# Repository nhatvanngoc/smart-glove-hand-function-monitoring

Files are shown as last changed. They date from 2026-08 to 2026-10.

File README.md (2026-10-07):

# NGHIÊN CỨU VÀ PHÁT TRIỂN GĂNG TAY THÔNG MINH HỖ TRỢ ĐÁNH GIÁ VÀ THEO DÕI CHỨC NĂNG VẬN ĐỘNG BÀN TAY TRONG PHỤC HỒI CHỨC NĂNG SAU ĐỘT QUỴ

> **Học sinh:** Văn Ngọc Nhật Anh (11A2) + Nguyễn Duy Quân (12A1) · **GVHD:** Lê Công Long · **Trường:** THPT Quảng Trị, Quảng Trị
> **Trạng thái hồ sơ:** pha **cơ sở lý thuyết & thiết kế** (`DEC-PHASE-001`) · **chưa có kết quả thực nghiệm** · **bản đã nộp:** [`docs/DE_CUONG.pdf`](docs/DE_CUONG.pdf) (15 trang, 2026-09-26)
> **Tên đã nộp = tên `DEC-TOPIC-019`** (dưới đây). Tên mới mà README ngày 2026-09-19 ghi là "chốt" (`DEC-TITLE-001`) **chưa từng được duyệt trong `DECISION_LOG.md`** → đã hạ thành đề xuất chờ hủy (`DEC-TITLE-002`); chi tiết: [`research/reviews/2026-09-27_decuong_pdf_sync.md`](research/reviews/2026-09-27_decuong_pdf_sync.md)

**Tên tiếng Anh (hồ sơ ISEF/ViSEF bản dịch):**

> *A low-cost smart glove with directional piezoresistive sensing for quantitative hand motor-function assessment and longitudinal monitoring in post-stroke rehabilitation*

**Phụ đề kỹ thuật (dùng ở đầu báo cáo, không nằm trong tên):**

> *Găng tay đo lực ép bên trên khung cứng + tầm vận động chủ động/thụ động từng ngón, kèm ngưỡng tin cậy đăng ký trước khi đo.*

**Lĩnh vực dự thi (đã nộp):** Hệ thống nhúng (Embedded Systems) · **Thời gian:** 09/2026–01/2027 · **Địa điểm:** phòng sáng tạo trường + nhà riêng · chờ `DEC-TEAM-001` phê chuẩn vào log.

**Câu nói với giám khảo (12 giây):**

> Một găng tay đo **lực ép theo hướng** ở từng ngón, chạy tại nhà, kèm **bộ tiêu chí khiến mỗi con số tự nói được nó có đáng tin hay không** — để khoảng trống giữa hai lần tái khám không còn là hộp đen.

---

## Mục lục

[1. Luận điểm của đề tài](#1-luận-điểm-của-đề-tài) ·
[2. Vấn đề, có số](#2-vấn-đề-có-số) ·
[3. Câu hỏi nghiên cứu và điều kiện giết](#3-câu-hỏi-nghiên-cứu-và-điều-kiện-giết) ·
[4. Nguyên lý hoạt động](#4-nguyên-lý-hoạt-động) ·
[5. Ba đại lượng dẫn xuất và quy tắc đơn vị](#5-ba-đại-lượng-dẫn-xuất-và-quy-tắc-đơn-vị) ·
[6. Phương pháp: bộ kiểm chứng 10 ngưỡng](#6-phương-pháp-bộ-kiểm-chứng-10-ngưỡng) ·
[7. Kế hoạch và ngân sách](#7-kế-hoạch-và-ngân-sách) ·
[8. Tính mới — và bộ tiêu chí đang dùng để tự chấm](#8-tính-mới--và-bộ-tiêu-chí-đang-dùng-để-tự-chấm) ·
[9. Giới hạn tự khai](#9-giới-hạn-tự-khai) ·
[10. Bằng chứng của chính hồ sơ này](#10-bằng-chứng-của-chính-hồ-sơ-này) ·
[11. Bản đồ repo](#11-bản-đồ-repo) ·
[12. Thiết lập & quy trình](#12-thiết-lập--quy-trình) ·
[13. Metadata repo GitHub](#13-metadata-repo-github)

---

## 1. Luận điểm của đề tài

Đề tài **không** tuyên bố một nguyên lý vật lý mới và **không** bán một nguyên mẫu. Nó tuyên bố ba thứ, theo thứ tự bảo vệ được giảm dần:

1. **Một kiến trúc cơ khí** — mảng áp trở đặt trên **vách cứng** của ốp ngón, cấu hình cầu vi sai hai vách (bản nộp: `R_ref = 10 kΩ` → INA333 G=10 → ADS1115 16-bit), để đo riêng **thành phần lực ép bên**: đại lượng tăng khi người bệnh chống lại tầm vận động, tức là thứ mà cảm biến gập góc *về bản chất* không phân biệt được.
2. **Một thiết kế phép đo** — `AROM` rồi `PROM` trên cùng ngón, cùng phiên, ở **hai tốc độ kéo** (vì phản ứng căng cơ phụ thuộc tốc độ). `GAP = PROM − AROM` (bản nộp 2026-09-26; README cũ ghi ngược dấu) chính là phép thử phân tách *"chưa cố"* khỏi *"bị giữ lại"*.
3. **Một lớp tự kiểm chứng** — ngưỡng `MDC`/`ICC`/`CV`/trôi **đăng ký trước khi đo**, mỗi phiên mang cờ `UNRELIABLE` khi vượt ngưỡng, và **lỗi được tiêm có chủ đích** trên rig để chứng minh cờ đó không phải đồ trang trí.

> **Câu chốt cho hội đồng:** phần (1) đã có tiền lệ ở tầng phần tử cảm biến, phần (2) là lựa chọn phương pháp luận, **phần (3) là phần đề tài này mạnh hơn cả một số công trình đã công bố** — và cũng là phần rẻ nhất để làm đúng.

## 2. Vấn đề, có số

| Đại lượng | Giá trị | Nguồn (đã kiểm) |
|---|---|---|
| Đột quỵ ở Việt Nam — hiện mắc | **1.541**/100.000 (95% UI 1.431–1.679) | *Global Epidemiology* 2025;9:100199 · [DOI](https://doi.org/10.1016/j.gloepi.2025.100199) |
| Mới mắc / tử vong | **222**/100.000/năm · **135.999** ca tử vong (dẫn đầu nhóm tim mạch) | như trên |
| Tổn thương vận động chi trên, giai đoạn sớm | **~80%** | Cochrane 2014 CD010820 (trích Langhorne 2009) · [DOI](https://doi.org/10.1002/14651858.CD010820.pub2) |
| Liệt chi trên hoàn toàn lấy lại chức năng hữu ích sau 6 tháng | **~50%** | như trên (trích Kwakkel 2003) |
| Còn vấn đề tay sau **4 năm** | **~50%** | như trên (trích Broeks 1999) |
| Độ tin cậy của việc **người bệnh tự đếm số lần tập** | `MDC ≈ 31 %`; đếm nhầm **100–200 lần/giờ** | *Sensors* 2022;22(18):6938 · [DOI](https://doi.org/10.3390/s22186938) |
| Giá hệ thống PHCN bàn tay tại nhà đã FDA chấp thuận | **350–6.000 USD** | *Device* (Cell Press) 2024 |

**Suy ra vấn đề:** di chứng bàn tay kéo dài **nhiều tháng đến nhiều năm**, trong khi nhịp đánh giá lâm sàng là **1–3 tháng**; và cách thay thế đang dùng (tự báo cáo) **đã được đo là không đủ tin cậy để làm đơn vị phân tích**. Khoảng giữa hai lần tái khám là một hộp đen — không biết có tập không, tập đúng hay sai, tiến bộ hay chững.

*(Con số "cỡ 1,5 triệu người đang sống sau đột quỵ ở Việt Nam" là **phép nhân của đề tài** từ tỉ lệ hiện mắc × dân số, không phải số in trong bài báo — nêu rõ như vậy ở mọi chỗ dùng nó.)*

## 3. Câu hỏi nghiên cứu và điều kiện giết

**RQ chính** (quyết định đề tài sống/chết):

> **R1.** Đáp ứng lực–hướng từ mảng áp trở trên vách khung có **đủ nhạy và đủ ổn định** để phát hiện thay đổi chức năng bàn tay theo tuần — **vượt trên** biên độ nhiễu/trôi của chính hệ thống đo — và **không** sinh ra cảnh báo tiến triển giả?

**RQ phụ:**

> **R2.** Dấu hiệu gập/duỗi có suy ra được **chỉ từ mẫu đáp ứng trên vách**, không cần encoder, và kết hợp được với góc IMU để tái tạo tư thế bàn tay đủ trung thực cho chuyên gia đọc?
> **R3.** Các chỉ số trích xuất có **đồng biến** với công cụ chuẩn (Box & Block / ARAT / lực kế cầm tay) ở mức đủ để dùng làm thông tin bổ sung giữa hai lần tái khám?

| RQ | Cửa quyết định | Nếu fail thì sao |
|---|---|---|
| R1 | **`GATE 0`** (bản nộp: `C1.2` + `C1.8` là hai ô giết, tương ứng `G0.1` + `G0.7` cũ) | Không có chuỗi số liệu nào để nói về diễn tiến → đề tài đổi thành **báo cáo phương pháp + kết quả âm tính** (vẫn nộp được, vẫn có giá trị) |
| R1 | **`GATE C`** (trôi 28 ngày, nhiệt–ẩm, tháo/lắp) | Dừng đề tài theo đúng nghĩa đã ghi trong `research/protocols/06` |
| R2 | `GATE A`/`GATE B` trên ≥ 1 ngón | Bỏ tái tạo 3D, giữ `GAP`/`EI` |
| R3 | **Chỉ sau IRB** — nằm ngoài phạm vi đề cương này | Không nêu giả thuyết R3 như kết quả; chỉ là thiết kế dự phòng |

**Điều đề tài không hỏi, và do đó không được claim:** không đo lực tuyệt đối trên ngón, không đo góc khớp tuyệt đối từ ADC, không đo hoạt động cơ, không chẩn đoán, không thay thế đánh giá lâm sàng, không cam kết hiệu quả phục hồi.

## 4. Nguyên lý hoạt động

```
Co cơ / bị duỗi thụ động ──► ngón ép vào VÁCH CỨNG của ốp ngón
   ► áp suất tiếp xúc p = F/A_c nén mảng Velostat
   ► ΔR/R = γ · Δp/p₀                       (γ = độ nhạy áp trở, p₀ = F_p/A_c)
   ► cầu vi sai hai vách: d = S(lòng) − S(mu), R_ref = 10 kΩ (bản nộp)
   ► INA333 G=10 ──► mux CD74HC4067 ──► ADS1115 16-bit (62,5 µV/LSB)
   ► ESP32-S3: IIR fc=10 Hz + Notch 50 Hz ──► BLE ──► Orange Pi 5 Pro
   ► auto-zero 3 s + ô tham chiếu + nhãn "Nghi vấn" (2 vòng lặp kín)
   ► EI · GAP · RAL          (KHÔNG phải newton, KHÔNG phải độ suy từ ADC)
```

**Hai kết quả rút ra từ mô hình, và cả hai đều kiểm chứng được bằng tay** (`docs/02` §5.5, `CLM-MET-003`):

1. `A_c` **triệt tiêu ở bậc nhất** ⇒ kích thước mảng **không** phải vấn đề tỉ số tín hiệu/nhiễu; nó là vấn đề cơ khí (áp suất phân bố lại, độ lặp lại khi tháo/lắp). ⇒ Không cần mua mảng to hơn.
2. Thiết kế chỉ sống trong một **cửa sổ tiền tải `F_p` chặn hai phía**: dưới thì không đủ nhạy — với `n_eff ≈ 11`, `V_EX = 3,1 V`, `LSB = 1,51 mV` và `ΔV ≥ 8 LSB` tại `ΔF = 1 N` thì `F_p ≤ 68·γ·ΔF` (γ = 0,5 ⇒ `F_p ≲ 34 N`); trên thì điện trở nguồn cao làm **mux không kịp ổn định ở 20 Hz**. **"Cửa sổ đó có rỗng không" chính là nội dung của GATE 0.**

> `100 kΩ / 10-bit / 1,51 mV` là **ngân sách thiết kế** trong `docs/04` §1, **không phải kết quả đo** — cấm dùng như số liệu.
> Bản nộp 2026-09-26 dùng chuỗi khác (`CLM-HW-003`, chờ `DEC-HW-005`): ADS1115 + INA333 + `R_ref = 10 kΩ` + SHT30 + 1 IMU LSM6DS3 — xem `docs/04` §8.
> Số học cửa sổ preload phải tính lại với LSB mới sau khi `DEC-HW-005` được chốt.

**Đính chính hai chỗ cũ trong README này:** (1) bản trước viết "thiết kế **không dùng IMU**" — đúng hơn: **dấu gập/duỗi** lấy từ mẫu vách mà không cần encoder (ý của `docs/01` §4), còn **góc và tốc độ kéo** thì bản nộp chỉ còn **1 IMU ở mu tay** (bù nghiêng), không còn 6 IMU đo góc khớp — **nguồn đo góc cho `GAP` là câu hỏi mở I7**, chờ `DEC-HW-005` trả lời. (2) bản trước viết `GAP = AROM − PROM` — **bản nộp quy ước `GAP = PROM − AROM ≥ 0°`**; đã sửa đồng bộ ở §5.

Phân cấp thuật ngữ (bắt buộc dùng đúng): [`docs/bao_cao/GLOSSARY.md`](docs/bao_cao/GLOSSARY.md) — **vật liệu Velostat** ≠ **sensing element** (Velostat + đồng tự dính + cấu trúc sandwich) ≠ **mảng sensing element** ≠ **hệ thống cảm biến** (mảng + ESP32-S3 + firmware).

## 5. Ba đại lượng dẫn xuất và quy tắc đơn vị

| Đại lượng | Định nghĩa (bản nộp 2026-09-26, `CLM-DEF-001` — chờ `DEC-METRIC-002` phê chuẩn) | Điều kiện phải in kèm | Đơn vị |
|---|---|---|---|
| **`EI`** (Effort Index) | trung vị biến thiên phổ của tín hiệu vi sai 12 kênh, chuẩn hóa theo vận tốc góc cùng phiên; công thức/cửa sổ/ngưỡng **cố định trước khi đo**, chỉ so sánh nội bộ cùng giao thức | ngón · tốc độ kéo · hướng dẫn bằng giọng nói | **không thứ nguyên** (công thức tường minh còn nợ) |
| **`GAP`** | **`PROM − AROM`** trên cùng ngón, cùng phiên (≥ 0°, theo giao thức; **không** tự suy nguyên nhân yếu/co cứng/khớp) | PROM kéo thụ động chậm · AROM gập chủ động tối đa · **hai tốc độ kéo** | độ — **nguồn đo góc còn mở (I7)**, **không** suy từ ADC |
| **`RAL`** | nấc tải **nhỏ nhất** (thang 120 g → 0 g) đạt tỉ lệ hoàn thành nhịp **P_complete ≥ 80 %** (10 chu kỳ gập/duỗi mỗi nấc, trên giàn + phantom) | tải (g) · vị trí khớp · tốc độ | **gam + bậc tải** (đặc trưng giao thức kiểm định, **không** phải bằng chứng hồi phục) |

**Cấm trong mọi bảng số:** `ADC → newton` (không có load cell trên ngón; load cell chỉ là chuẩn đối chứng ở rig) · `ADC → độ` · dùng `RAL` như chỉ số lâm sàng.
> Lịch sử định nghĩa (để không lẫn khi đọc tài liệu cũ): README/`DE_CUONG_NOP_TRUONG.md` cũ ghi `GAP = AROM − PROM`, `EI = median\|d\|/(1+κ\|v̂\|)`, `RAL = thực/yêu cầu ∈ [0,1]`; `docs/02` §7.3 ghi `GAP` mẫu chuẩn hóa, `EI = E/(E+E_nền)` — xem sổ R2–R4 trong sync review §5.3.

## 6. Phương pháp: bộ kiểm chứng 10 ngưỡng (bản nộp: M1–M6 + C1.1–C1.10)

> Ngưỡng được viết ra và **đóng chốt trước khi có bất kỳ số liệu nào**, và **không** chỉnh lại sau khi thấy số. Một ngưỡng không đạt ⇒ báo cáo **fail** ở ngưỡng đó. Cấm viết "GATE 0 pass" khi `C1.2` hoặc `C1.8` fail. Bảng dưới là ngưỡng **đã nộp** (`CLM-MET-005`, chờ `DEC-METRIC-002` phê chuẩn); cột cuối ghi chỗ đổi so với bộ G0.x cũ.

| ID (nộp) | Câu hỏi | Ngưỡng đã nộp | Đổi so với G0.x |
|---|---|---|---|
| **C1.1** | Sàn nhiễu mạch đo là bao nhiêu? | `Vpp ≤ 5 mV` / 5.000 mẫu tĩnh | chốt luôn định nghĩa B + ngưỡng tuyệt đối |
| **C1.2** 🎯 | Có tồn tại `F_p` vừa đủ nhạy vừa đủ ổn định? | `SNR ≥ 18 dB` (≈8×) tại `ΔF = 1 N`, ≥10/12 kênh | đơn vị LSB → dB, phạm vi 10/12 kênh |
| C1.3 | Mảng có thật sự là áp kế? | `γ ≥ 0,25` (≥10/12 kênh), `R² ≥ 0,90` | **R² 0,95 → 0,90** |
| C1.4 / C1.5 | Lặp lại giữa chu kỳ / giữa **ngày**? | `CV ≤ 5 %` · `CV ≤ 8 %` (3 ngày, tháo/đeo lại, trên phantom) | **ICC → CV**, nới 5 %→8 % |
| C1.6 / C1.7 | Đường lên có trùng đường xuống? Có bị lún khi giữ tải? | `h ≤ 18 %` · `creep ≤ 8 %` (giữ 60 s @ 5 N) | **15 %→18 %** · **đổi định nghĩa creep** |
| **C1.8** 🎯 | Tín hiệu có trôi chậm hơn biên độ cần đo? | trôi/tín hiệu ≤ 2,0 sau 10 ngày (qua auto-zero) | **bỏ** điều kiện so ΔV@1N |
| C1.9 | Các mảng có đủ giống nhau để so sánh giữa ngón? | độ rải `γ ≤ ±40 %` (+ bảng chuẩn hóa) | khớp |
| C1.10 | Cấu hình kênh đọc kịp không? | `fs ≥ 20 Hz` đồng thời 12 kênh | khớp (⚠️ PDF §8.1/§9.1 ghi 50 Hz — I1) |

🎯 = ô giết đề tài. **Cách chạy GATE 0 mà không cần một dòng code:** `research/protocols/08a` — phiếu in được, chuẩn lực là **khối lượng đã cân** (`F = m·g`, không trễ, không cần hiệu chuẩn điện tử), mọi phép tính chỉ là trừ số nguyên. Kế hoạch đầy đủ + cây fail: `research/protocols/08` (giữ 10 ô chờ chốt; bảng đối chiếu G0↔C1: sync review §4).

## 7. Kế hoạch và ngân sách

```
Lớp 0 (GATE 0)    Mảng Velostat + đồng tự dính + jig in + khối lượng chuẩn + đồng hồ đo
                  ── chuẩn lực = F = m·g, KHÔNG cần load cell ──►  0,12–0,65 triệu đ
Lớp 1 (GATE A/B)  3 ngón (cái, trỏ, giữa) × 2 khớp, cầu vi sai hai vách + 1 IMU LSM6DS3
                  + INA333 + ADS1115 + 2×CD74HC4067 → ESP32-S3 (20 Hz)  ► +0,57–1,50 triệu đ
Lớp 2 (GATE D/F)  Orange Pi 5 Pro (log nguồn thô + dashboard) + rig E4/E5 (vít me,
                  phanh từ, tải chuẩn) + phantom silicone          ► +1,10–2,50 triệu đ
Lớp 3 (lâm sàng)  IRB + bệnh viện + n ≥ 20                          ► CHƯA MỞ — ngoài đề cương
```

> Bản nộp đặt thêm 3 ràng buộc sản phẩm: giá găng mục tiêu **< 1,5 triệu đ** · khối lượng đeo **< 150 g** · trễ toàn hệ thống **≤ 500 ms** (M5).

| Tổng hợp | Tiền mặt cần chi (vật tư đã có sẵn đã được trừ) |
|---|---|
| Hết GATE 0 | **0,12–0,65 triệu đ** |
| Hết GATE A+B | + 0,57–1,50 triệu đ |
| Hết GATE F | ≈ **1,8–4,7 triệu đ** |
| Kịch bản phải mua tất cả | ≈ 6,5–12 triệu đ |
| **Chi phí tối đa nếu GATE 0 fail** | **≤ 0,65 triệu đ** — thiết kế để cắt lỗ sớm |

Quy tắc: mỗi lớp **chỉ mở khi lớp trước pass**; vật tư được cấp/đã có ghi là **"được cung cấp"**, không ghi thành "chi phí 0 đ"; giá thương mại chỉ là **mốc so sánh có nguồn**, không phải giá của đề tài. Bảng theo hạng mục: `docs/DE_CUONG_NOP_TRUONG.md` §7; trạng thái vật tư: `research/context/EQUIPMENT_AND_ACCESS.md`.

**Kế hoạch theo cửa, không theo lịch thi** (repo **không có ngày nộp**, và không ai được bịa một cái): 8 pha từ "chốt ngưỡng → GATE 0 → A → B → C → D → E → F", chi tiết `research/protocols/06`–`08`.

## 8. Tính mới — và bộ tiêu chí đang dùng để tự chấm

> **Bộ tiêu chí: ViSEF/ISEF**, không phải tạp chí kỹ thuật. Đề tài **không** có nguyên lý mới và không tự đo mình bằng chuẩn cần nguyên lý mới + dataset + đối chứng lâm sàng. Mọi nhận định "mới/không mới" phải kèm tên bộ tiêu chí (`DEC-NOV-001` chờ chủ dự án chốt mức).

| Hướng được coi là mới | Kiểm chứng ngược đã làm | Kết luận hiện hành |
|---|---|---|
| Vách cứng phân biệt hướng lực | Phần tử áp điện trở **trên vách** có từ **2015** (`SRC-SIDEWALL-PIEZO-2015`); vỏ cứng khớp nối + da áp điện trở **2026** (`SRC-ARTGLOVE-2026`, 2048 taxel, 22 DoF) | **Cải tiến cấu hình + cách lập luận**, không phải nguyên lý |
| Găng đo lực cho người đột quỵ | Đối thủ gần nhất: Lin et al., *Sensors* 2022;22(19):7212 — **19 IMU + 1 bóng áp lực**, n = 14, **có IRB** | Họ thắng về **học máy + cỡ mẫu**; đề tài phải thắng ở **cơ khí tạo phân tách + lớp tin cậy**, không ở số cảm biến |
| Găng có chức năng tập/hỗ trợ | ironHand (JRATE 2016 **và** J Rehabil Med 2018;50:598–606, n = 5, **không** dùng thiết bị đo lực chuẩn hoá làm kết quả chính) | Đề tài **bỏ** chức năng tác động để dồn vào phép đo |
| Ghi nhận tại nhà thay cho tự báo cáo | Manumeter (RCT, n = 20, *Sensors* 2022) — MDC 31 %, 100–200 đếm nhầm/giờ | Đây là **bằng chứng cho khoảng trống**, không phải cho thiết bị của ta |
| "Hệ thống đầu tiên" | Khảo sát hệ thống găng tự chế (arXiv 2405.15417) + găng đo từ 2006 + Neofect Smart Glove (132 g, flex + 9 DoF, dashboard cho chuyên gia) | **Cấm nói.** Mẫu câu duy nhất được phép: *"chưa tìm thấy công trình nào kết hợp [A+B] cho [nhóm X]"*, và chỉ khi đã có số tự đo |

Bằng sáng chế đã tra: **US20150233779A1** (Waltop) — **đã abandoned**; **CN116954366A** (ĐH Đông Nam Á) — **pending**. FTO = `PARTIAL` vì **chưa đọc toàn văn điểm yêu cầu bảo hộ** ⇒ chỉ được nói "đã tra cứu, không phát hiện xung đột trực tiếp". Chi tiết + nghĩa vụ trích dẫn: `research/reviews/2026-09-19_prior_art_novelty_gate1.md`.

## 9. Giới hạn tự khai

| # | Giới hạn | Cách đề tài xử lý |
|---|---|---|
| 1 | **Chưa có một kết quả đo nào** | nêu ngay đầu README và đầu đề cương; không nói vòng quanh |
| 2 | Chưa hiệu chuẩn `ΔR → N`; ADC không quy đổi ra newton/độ | dùng counts + `EI` không thứ nguyên |
| 3 | Đối tượng tự kiểm chứng ban đầu là **một người** (chính người chế tạo) | chặn mọi kết luận lâm sàng tới khi có IRB + n ≥ 20 |
| 4 | Velostat phi tuyến, trễ, từ biến, trôi, nhạy ẩm | biến thành ngưỡng đo được (G0.5–G0.7), không tuyên bố đã khắc phục |
| 5 | Không có bằng chứng hiệu quả lâm sàng | tuyên bố dừng ở "cung cấp phép đo đáng tin" |
| 6 | `RAL` không phải chỉ số lâm sàng | chỉ dùng để so sánh cấu hình máy + chứng minh phát hiện lỗi |
| 7 | `GAP`/`EI` không thay thế FMA/ARAT/MAS | mục tiêu là **tần suất đo**, không phải thay công cụ chuẩn |

## 10. Bằng chứng của chính hồ sơ này

| Loại | Số lượng | Kiểm ở đâu |
|---|---|---|
| Nguồn đã vào sổ, có locator + mức đã đọc | **147** | `research/evidence/SOURCE_LEDGER.csv` |
| Tuyên bố, kèm cấp bằng chứng + hành động còn lại | **27** | `research/claims/CLAIM_LEDGER.csv` |
| Quyết định có ngày + chủ sở hữu + trạng thái | **38** | `research/context/DECISION_LOG.md` |
| Nhật ký truy vấn ngoài (**kể cả lần tìm không thấy**) | **81** | `research/queries/QUERY_LOG.jsonl` |
| Phiếu đo/thực nghiệm đã thiết kế, chưa chạy | **10 ngưỡng · 7 gate · 8 buổi bench** | `research/protocols/06`–`08a` |
| Số liệu đo của đề tài | **0** | `research/bench/logs/` — đang trống, và đó là trạng thái thật |

Quy tắc chống tự nâng cấp: **không** nâng mức bằng chứng; **một lần tìm không thấy = `UNVERIFIED`**, không phải "không tồn tại"; số liệu giả lập phải dán nhãn giả lập; agent đề xuất, **chủ dự án phê duyệt**. Toàn bộ ở [`AGENTS.md`](AGENTS.md).

## 11. Bản đồ repo

| Nhóm | File | Vai trò |
|---|---|---|
| **Nộp trường** | [`docs/DE_CUONG_NOP_TRUONG.md`](docs/DE_CUONG_NOP_TRUONG.md) | Đề cương hoàn chỉnh: 4 trụ + M1–M6 + ngân sách + hạn chế tự khai + Phụ lục A chống-claim |
| Đề tài | [`docs/01_Topic_Definition.md`](docs/01_Topic_Definition.md) | Tên đã chốt, vấn đề, khoảng trống, RQ1–R3, phạm vi (`A.4`: **không** phải thiết bị điều trị) |
| Lý thuyết | [`docs/02_Theoretical_Foundation.md`](docs/02_Theoretical_Foundation.md) | Sinh lý hồi phục, thang đo, cơ sinh học, vật liệu áp trở, mô hình §5.5, `EI`/`GAP`/`RAL`, INT8 |
| Prior art & sáng chế | [`docs/03_Literature_Gap_Analysis_Plan.md`](docs/03_Literature_Gap_Analysis_Plan.md) | Kế hoạch rà soát 2011–2026; §7 phương pháp tra cứu sáng chế + hồ sơ thất bại |
| Phần cứng | [`docs/04_Hardware_Architecture.md`](docs/04_Hardware_Architecture.md) | Kênh, MUX, ngân sách nhiễu/độ phân giải (**ngân sách thiết kế**, không phải kết quả) |
| Cơ khí — khung ốp ngón | [`hardware/cad/finger_shell_hinge/`](hardware/cad/finger_shell_hinge/README.md) | **Đề xuất** (`CLM-HW-004`/`DEC-HW-006`, chưa in/chưa đo): khung ốp 1 đốt ngón kiểu vỏ-sò, bản lề trục + ngàm cài, thay cơ chế xỏ ngón + bu-lông kẹp — CAD tham số CadQuery, xuất STEP/STL |
| Soạn thảo | [`docs/05_De_Cuong_Dang_Ky_DRAFT.md`](docs/05_De_Cuong_Dang_Ky_DRAFT.md) | **Outline nội bộ** (không nộp) + §8b các chỗ chủ dự án cần sửa |
| Mẫu báo cáo | [`docs/OUTLINE_BAOCAO_VISEFD.md`](docs/OUTLINE_BAOCAO_VISEFD.md) · [`docs/bao_cao/`](docs/bao_cao/) | Khung A/B/C + A.1–A.7 + GLOSSARY |
| Kiểm chứng | [`research/protocols/06`](research/protocols/06_glove_hand_GATE_experiment.md) · [`07`](research/protocols/07_ral_phantom_and_ktv_interview.md) · [`08`](research/protocols/08_gate0_execution_plan.md) · [`08a`](research/protocols/08a_gate0_bench_sheets.md) | Master 7 gate · RAL/phantom + phiếu tham khảo chuyên gia · kế hoạch GATE 0 · **phiếu đo in được, không code** |
| Vật tư & tiếp cận | [`research/context/EQUIPMENT_AND_ACCESS.md`](research/context/EQUIPMENT_AND_ACCESS.md) | Đã có / chưa chắc / cần mua + 4 bước chạy GATE 0 |
| Đánh giá chiến lược | [`research/reviews/2026-09-19_project_ceiling.md`](research/reviews/2026-09-19_project_ceiling.md) | Trần theo từng trục + **nguyên tắc giải ngân theo lớp** + quy tắc dừng |
| Benchmark | [`research/reviews/2026-09-19_benchmark_xe_lan_ALS_QG2025.md`](research/reviews/2026-09-19_benchmark_xe_lan_ALS_QG2025.md) | **Nội bộ.** Kiểm đếm một báo cáo từng giải Nhất quốc gia → định cỡ hình thức 15–20 trang, ≥1,3 ảnh/bảng mỗi trang. **Cấm trích trong hồ sơ nộp** (`DEC-SCOPE-003`) |
| Nhật ký đo | [`research/bench/logs/`](research/bench/logs/) | Một file mỗi buổi; **bản gốc không bao giờ bị sửa**; header nhắc lại ngưỡng đã chốt |
| Chỉ mục | [`INDEX.md`](INDEX.md) · [`research/README.md`](research/README.md) · [`AGENTS.md`](AGENTS.md) | Sơ đồ file, quy ước workspace, luật của repo |

## 12. Thiết lập & quy trình

Yêu cầu: Git, Python 3.10+, Bash.

```bash
python3 -m venv .venv && . .venv/bin/activate
python -m pip install --upgrade pip && python -m pip install -r requirements.txt
bash scripts/bootstrap_research_tooling.sh
python scripts/check_research_environment.py --strict
python scripts/build_context_bundle.py --budget-chars 40000     # -> research/generated/ (đã gitignore)
```

**Ba việc còn lại, đúng thứ tự:**

1. ☐ **Chủ dự án chốt 6 quyết định đồng bộ bản nộp** (`DEC-SYNC-001`/`TEAM`/`TITLE-002`/`HW-005`/`METRIC-002`/`SCOPE-005`, sync review §6) **rồi chốt 10 ô** `Chốt?` trong `research/protocols/08` §7 (việc này **không** ai làm thay được).
2. ☐ Chạy GATE 0 bằng `research/protocols/08a` → mỗi buổi = 1 file log + 8 ảnh; **kể cả buổi fail cũng phải lưu**.
3. ☐ Thay dự toán bằng **báo giá/hoá đơn thật** → `DEC-BUDGET-001` (id dự kiến trong `2026-09-19_project_ceiling.md`, chưa tạo); chỉ khi đó mới xét giải ngân Lớp 1.

Luồng chuẩn cho mỗi thay đổi lớn: đọc `research/context/PROJECT_SNAPSHOT.md` → log truy vấn (`scripts/research_log.py`) → cập nhật `SOURCE_LEDGER`/`CLAIM_LEDGER` → chạy review protocol → cập nhật snapshot + `INDEX.md` → dựng lại bundle.

## 13. Đổi tên repo + metadata GitHub (chủ dự án chạy — agent không có quyền Administration)

Repo hiện tên `smart-glove-hand-function-monitoring` với **description vẫn là mô tả đề tài cũ**. Bốn lệnh dưới đây chạy theo thứ tự, copy nguyên khối được:

```bash
# 1) Doi ten repo cho khop ten de tai moi (quyen admin cua chu du an)
gh repo rename stroke-hand-monitoring-glove --repo nhatvanngoc/smart-glove-hand-function-monitoring

# 2) Cap nhat remote cua may local theo ten moi
git remote set-url origin https://github.com/nhatvanngoc/stroke-hand-monitoring-glove.git
git push -u origin HEAD

# 3) Mo cua cho cai ten moi: description + topic + homepage (xoa topic cu neu can)
gh repo edit --description "Nghiên cứu, thiết kế găng tay giám sát và đánh giá khả năng vận động bàn tay trong phục hồi chức năng chủ động sau đột quỵ — giai đoạn cơ sở lý thuyết, chưa có kết quả đo; toàn bộ prior art có DOI tại research/evidence/" \
  --add-topic stroke --add-topic rehabilitation --add-topic hand-function --add-topic wearable-sensors \
  --add-topic piezoresistive --add-topic velostat --add-topic esp32-s3 --add-topic isef --add-topic visef

# 4) kiem tra
gh repo view --json name,description,repositoryTopics -q '"\(.name)\n\(.description)\nTopics: \([.repositoryTopics[].name]|join(", "))"'
```

**Nếu không muốn đổi tên repo**, chỉ chạy bước 3 (description/topics) — README và tên đề tài trong repo đã khớp nhau, GitHub redirect tự động nếu sau này đổi tên.

*Ba lựa chọn tên repo, xếp theo khuyến nghị:* `stroke-hand-monitoring-glove` (đúng 3 từ khoá: đối tượng – việc – thiết bị) · `hand-motion-glove` (ngắn, dễ nhớ, hơi rộng) · `smart-glove-stroke-rehab` (dễ đọc nhưng giữ chữ "smart" mà tên đề tài mới đã bỏ).

---

### Lịch sử cập nhật gần nhất

| Ngày | Việc |
|---|---|
| 2026-09-27 | **Đồng bộ bản nộp `docs/DE_CUONG.pdf` (2026-09-26):** đội hình 2 người + GVHD + timeline + lĩnh vực Nhúng; tên quay về `DEC-TOPIC-019` (`DEC-TITLE-001` chờ hủy); `GAP = PROM − AROM`; ngưỡng C1.x; kiến trúc ADS1115+INA333; +7 nguồn/+3 claim; 6 quyết định chờ chốt (`DEC-SYNC-001`…`DEC-SCOPE-005`) |
| 2026-09-19 (lượt 4) | README dựng lại theo cấu trúc hồ sơ khoa học (luận điểm · RQ + điều kiện giết · nguyên lý · 10 ngưỡng · tự khai); đề xuất tên mới (ghi nhầm là "chốt" — đã sửa 2026-09-27, chờ `DEC-TITLE-002`) |
| 2026-09-19 (lượt 3) | Đề cương nộp `docs/DE_CUONG_NOP_TRUONG.md`; sửa 2 lỗi trích dẫn trong `A.1`; thi hành `DEC-ROLE-001` (không nêu danh tính người được tham khảo) |
| 2026-09-19 (lượt 1–2) | Prior art lượt 1–2 (novelty dịch từ cơ chế sang lớp thống kê); GATE 0 plan + phiếu đo không code; đánh giá trần dự án + mức đầu tư theo lớp |

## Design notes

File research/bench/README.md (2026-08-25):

# Bench metrology execution area

This directory contains **empty templates and validation tooling only**. It contains no hardware measurement and must never be cited as a result.

## Gate-2 execution preconditions

1. A traceable/characterized reference load cell or test fixture is available.
2. The sensor unit, electrode layout, conditioning circuit, ADC reference, scan order and firmware hash are recorded.
3. Raw ADC and reference timestamps can be retained together.
4. The protocol operator completes `templates/session_manifest.csv` and `templates/perturbation_log.csv` without participant identifiers.
5. Reference-load calibration and nominal repeatability are run before any perturbation is interpreted.

`templates/` contains headers only. Raw measurements, photos, private subject mappings, downloaded tools and generated analysis outputs follow repository ignore/privacy rules and must be stored outside tracked templates until an owner-approved data-management plan exists.

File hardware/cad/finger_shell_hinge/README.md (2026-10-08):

# Khung ốp 1 đốt ngón tay — cơ chế BẢN LỀ + NGÀM CÀI (thay cơ chế "xỏ ngón vào ống kín")

> **Trạng thái:** `PROPOSED` — bản vẽ CAD tham số, **chưa in, chưa đo lực/preload thật, chưa có người dùng thử**.
> **Claim/quyết định liên quan:** `CLM-HW-004` (`research/claims/CLAIM_LEDGER.csv`), `DEC-HW-006` (`research/context/DECISION_LOG.md`).
> **Phạm vi:** làm đúng **1 đốt ngón tay trước** (theo yêu cầu), chưa nhân ra 3–5 ngón.
> Theo `AGENTS.md`: đây là **thiết kế cơ khí trên giấy**, không phải kết quả đo, không phải tuyên bố "đã hết đau/đã thoải mái" — mọi tính từ công thái học (thoải mái, nhanh, không đau) đều là **mục tiêu thiết kế cần kiểm chứng sau khi in**, không phải kết luận.

---

## 1. Vấn đề đang muốn sửa

Thiết kế ốp ngón hiện có trong `docs/04_Hardware_Architecture.md` (§6, §8) là một **ống gần như kín**, có **bu-lông kẹp vi chỉnh preload** siết quanh ngón tay để ép hai vách cảm biến (Velostat) vào hai bên lòng/mu ngón. Nhược điểm với đúng nhóm người dùng của đề tài (sau đột quỵ, bàn tay liệt/co cứng, khó chủ động gập — xem `README.md` §1 mục tiêu đề tài):

- Phải **luồn/ép đốt ngón co cứng qua một vòng gần kín** → đau, khó, nhiều khi cần 2 người.
- Siết bu-lông quanh ngón đang co cứng → khó canh lực, dễ siết lệch, dễ gây khó chịu thêm.

**Yêu cầu của chủ dự án (nguyên văn rút gọn):** "trên đốt ngón có 1–2 bản lề, mở ra để đặt khung vào phía trên tay bệnh nhân, bên dưới chỉ cần cài lại — bệnh nhân không phải cố xỏ ngón tay vào một cách đau đớn."

→ Bài toán cơ khí: biến ống kín thành **vỏ-sò (clam-shell)** có 1 cạnh mở được (bản lề) và 1 cạnh khóa nhanh (ngàm cài), vẫn giữ được 2 vách cứng đối xứng (mu/lòng) để dán sensing element như kiến trúc đo vi sai đã chọn (`docs/04` §3.2, "mỗi khớp có cặp sensing element đối xứng trên hai vách đối diện").

## 2. Tham khảo thị trường (tham khảo nguyên lý — KHÔNG sao chép hình học)

| Sản phẩm/khái niệm | Nguyên lý lấy làm tham khảo | Khác với thiết kế ở đây |
|---|---|---|
| **Oval-8® Finger Splint** (nẹp ngón PIP/DIP bán thương mại) — [AliMed](https://www.alimed.com/products/oval-8-finger-splint) (`SRC-OVAL8-ALIMED`) | "Open design eliminates skin issues and discomfort" — vòng **hở sẵn một khe**, lắp bằng cách lách qua khe đàn hồi, không phải xỏ kín từ đầu ngón | Oval-8 là **một khối nhựa đàn hồi duy nhất** (tự bung ra rồi tự khép lại nhờ độ đàn hồi vật liệu), không có bản lề trục hay ngàm cài rời. Thiết kế ở đây dùng **bản lề trục in 3D + chốt** vì PETG/PLA không đàn hồi tốt như nhựa nhiệt dẻo y tế của Oval-8 → không thể chỉ dựa vào lò xo vật liệu để vừa giữ chặt vừa dễ mở. |
| **Nẹp ngón nhiệt dẻo 2 mảnh** — [Cults3D / RafaelNaranjo](https://cults3d.com/en/3d-model/various/finger-orthosis-thermoformable-3d-printed-rafaelnaranjo) (`SRC-FINGERORTHO-CULTS3D`) | 2 mảnh cứng nối bằng vùng mềm, cố định bằng **dây chun/Velcro xuyên khe** | Thiết kế ở đây giữ ý tưởng "khe xuyên dây đai" làm **lớp khóa an toàn phụ** (mục 6), nhưng khóa chính là ngàm cơ khí chứ không phải dây đai. |
| **HERO Grip Glove** (robot hỗ trợ bàn tay sau đột quỵ, PMC7045638) (`SRC-HEROGLOVE-PMC2020`) | Benchmark công thái học: **don < 5 phút, doff < 1 phút**, thiết kế riêng cho tay liệt/co cứng, không cần tự chủ động gập để đeo | Dùng làm **mốc so sánh mục tiêu** (không phải của thiết bị này) cho tiêu chí "thời gian mang/tháo" đã nêu ở `docs/04` §6. |
| Bản lề khớp ống in 3D kiểu "piano hinge" (kiến thức phổ biến trong cộng đồng in 3D, không gắn với 1 sản phẩm cụ thể) | Khớp ống so le (knuckle) + chốt rời — in được bằng FDM mà không cần vật liệu đàn hồi | Áp dụng trực tiếp cho cạnh bản lề của khung ốp. |

**Tra cứu bằng sáng chế:** chưa thực hiện cho riêng cơ cấu bản lề/ngàm này (khác phạm vi với tra cứu `US20150233779A1`/`CN116954366A` đã ghi ở `README.md` §8, vốn là về *mảng cảm biến*, không phải *cơ cấu kẹp cơ khí*). Cơ cấu bản lề-ngàm nói chung là kỹ thuật phổ biến trong hộp/vỏ nhựa và nẹp y tế; **FTO cho riêng chi tiết này chưa tra**, không tuyên bố mới.

## 3. Nguyên lý cơ cấu đề xuất

```
                    CẠNH BẢN LỀ (trái)             CẠNH NGÀM CÀI (phải)
                   ┌──────────────┐               ┌──────────────┐
  Nửa MU TAY (A)   │  3 khớp ống   │   vách cứng   │  khối ngàm    │
  — cố định,       │  (knuckle)    │  + hốc dán    │  2 nấc răng   │
  đặt lên trước    │  xen kẽ với B │  Velostat     │  (cố định)    │
                   └──────┬───────┘               └──────┬───────┘
                          │ chốt Ø2mm xuyên suốt          │
  Nửa LÒNG TAY (B) ┌──────┴───────┐               ┌──────┴───────┐
  — xoay quanh     │  2 khớp ống   │   vách cứng   │  tay đòn đàn  │
  bản lề để đóng   │  (knuckle)    │  + hốc dán    │  hồi, có móc  │
                   └──────────────┘               └──────────────┘

  Thao tác: (1) đặt đốt ngón vào lòng nửa A (đang để hở, B đang mở ra ~150°)
            (2) gập B xuống quanh trục chốt
            (3) ấn nhẹ tay đòn ở B cho móc "tách" vào 1 trong 2 nấc răng của A
            (4) (tuỳ chọn) luồn dây đai/Velcro qua khe phụ ở 2 đầu để khóa an toàn lớp 2
  Mở ra: lấy ngón tay ra bằng cách bẩy nhẹ tay đòn ra khỏi nấc răng — không cần tháo chốt.
```

Ảnh xem nhanh (dựng từ STL, xem thêm trong `out/renders/`):

| Trạng thái MỞ | Trạng thái ĐÓNG |
|---|---|
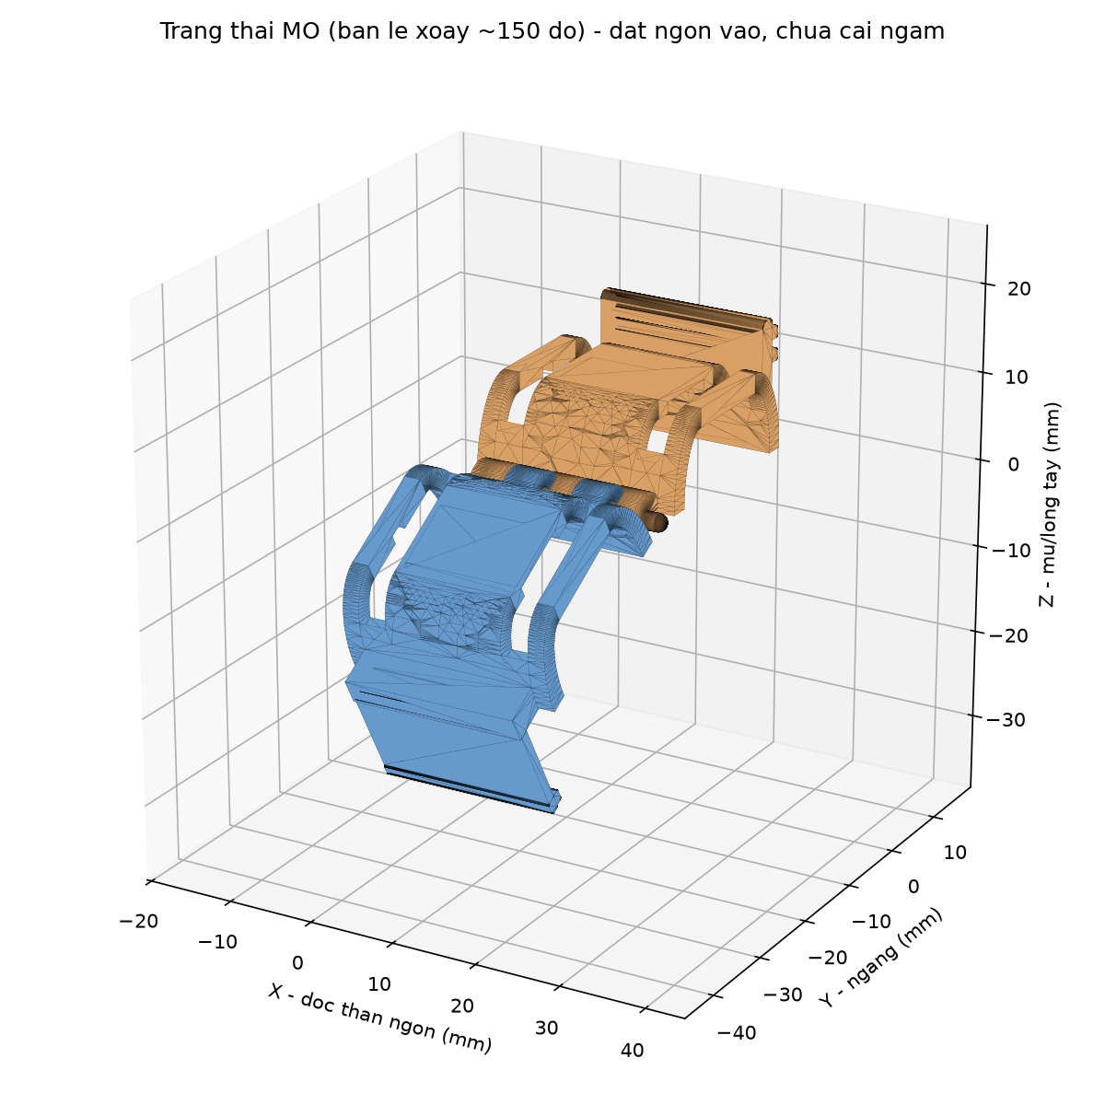
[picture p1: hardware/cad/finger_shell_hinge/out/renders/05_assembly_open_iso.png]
open
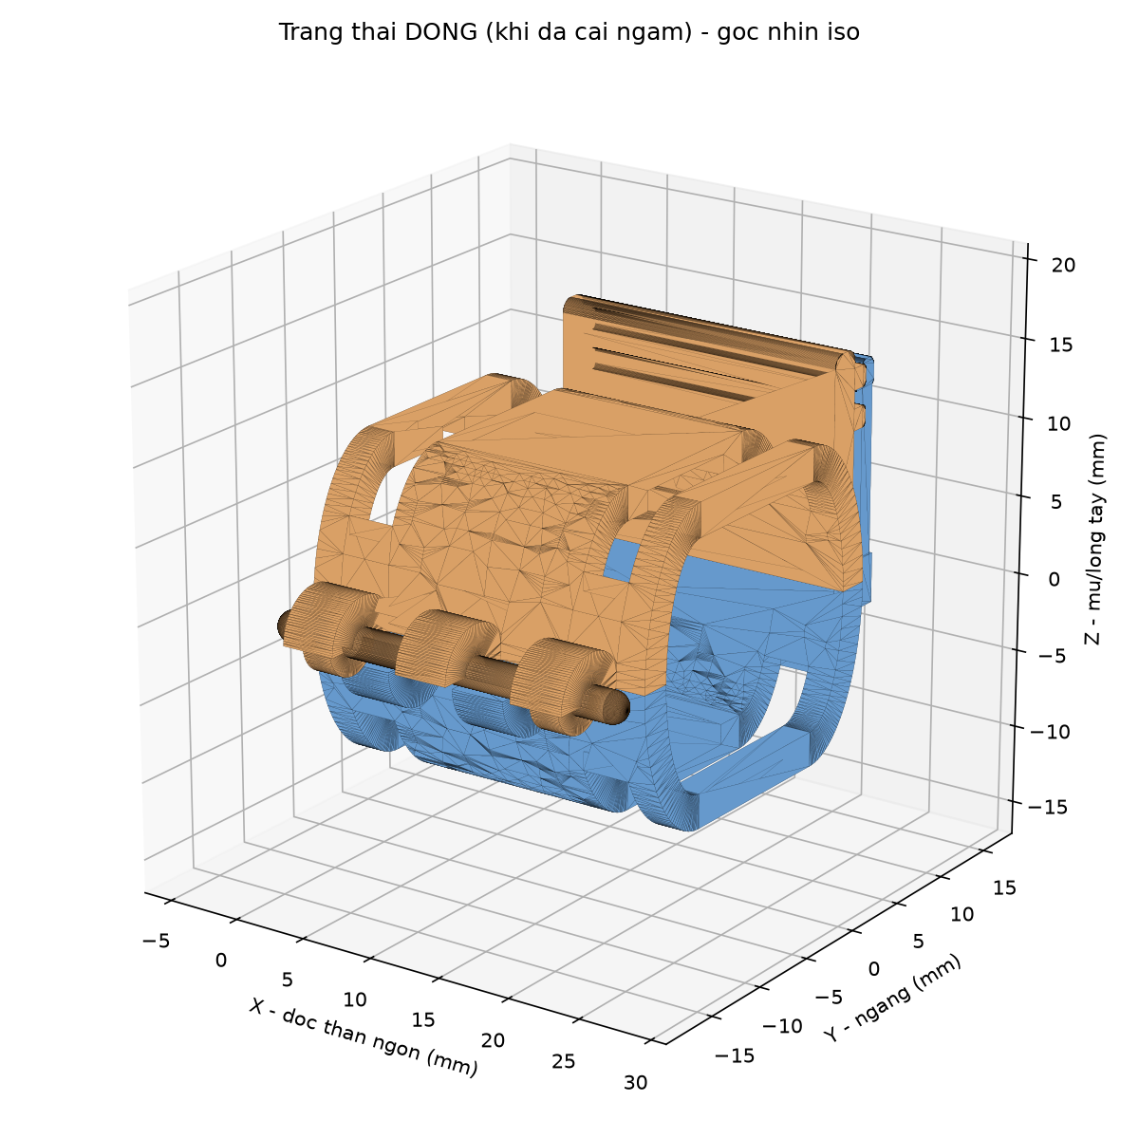
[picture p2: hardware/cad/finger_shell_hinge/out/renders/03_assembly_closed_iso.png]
closed
|  |  |
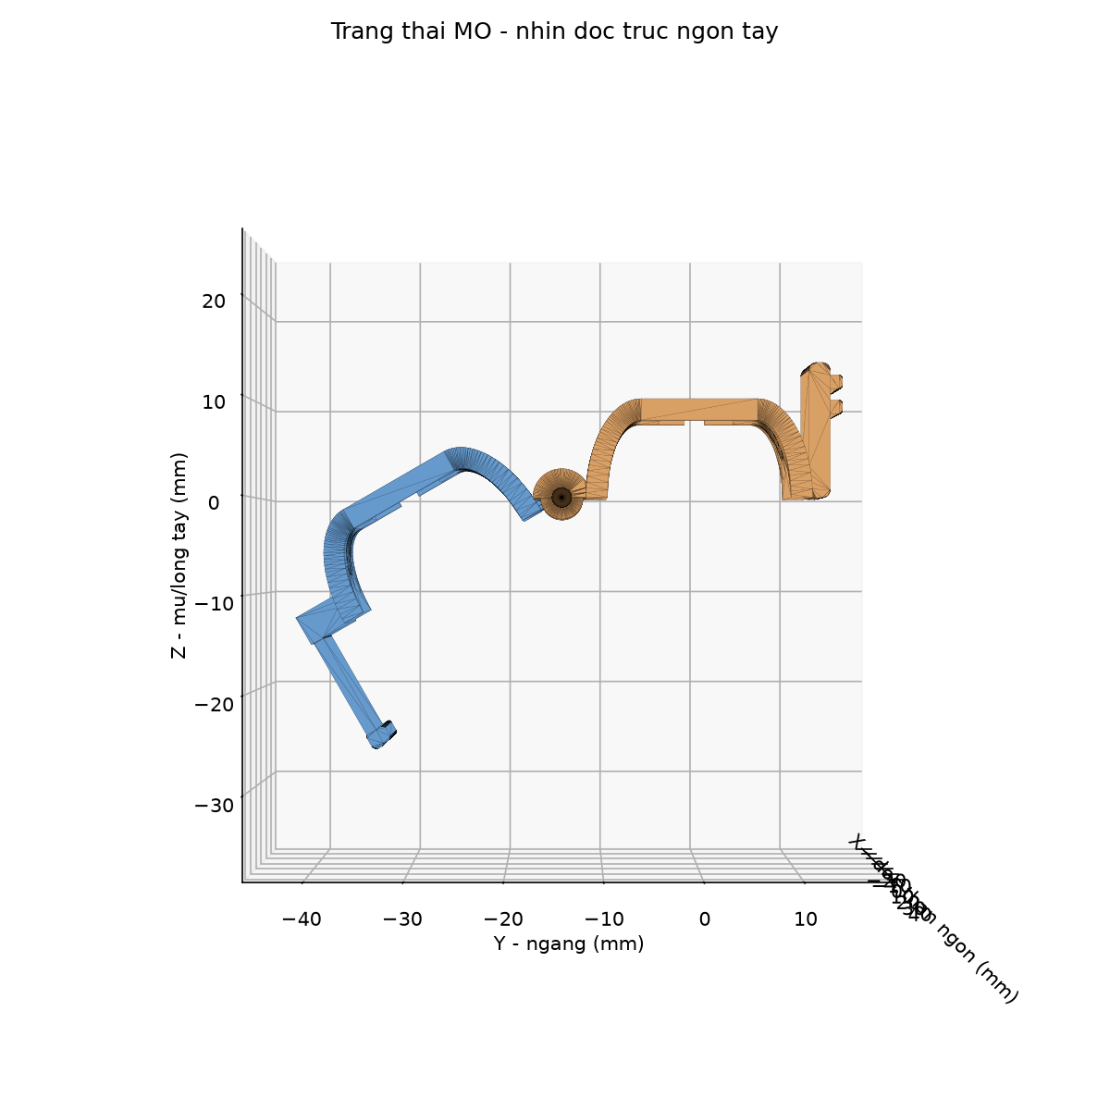
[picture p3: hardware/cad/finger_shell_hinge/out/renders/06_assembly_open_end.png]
open-end
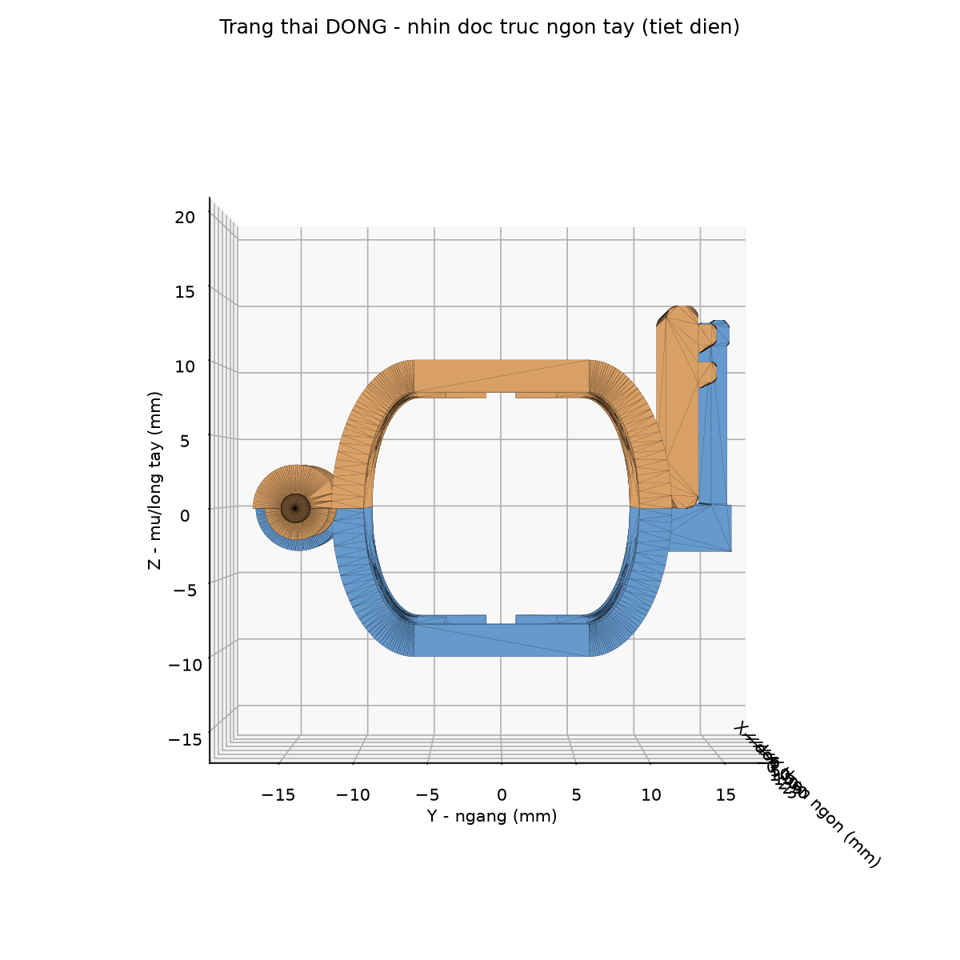
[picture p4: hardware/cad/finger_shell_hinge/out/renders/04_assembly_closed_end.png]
closed-end
|  |  |

Từng mảnh riêng:

| Nửa mu tay (A, cố định, mang khối ngàm) | Nửa lòng tay (B, xoay quanh bản lề, mang tay đòn) |
|---|---|
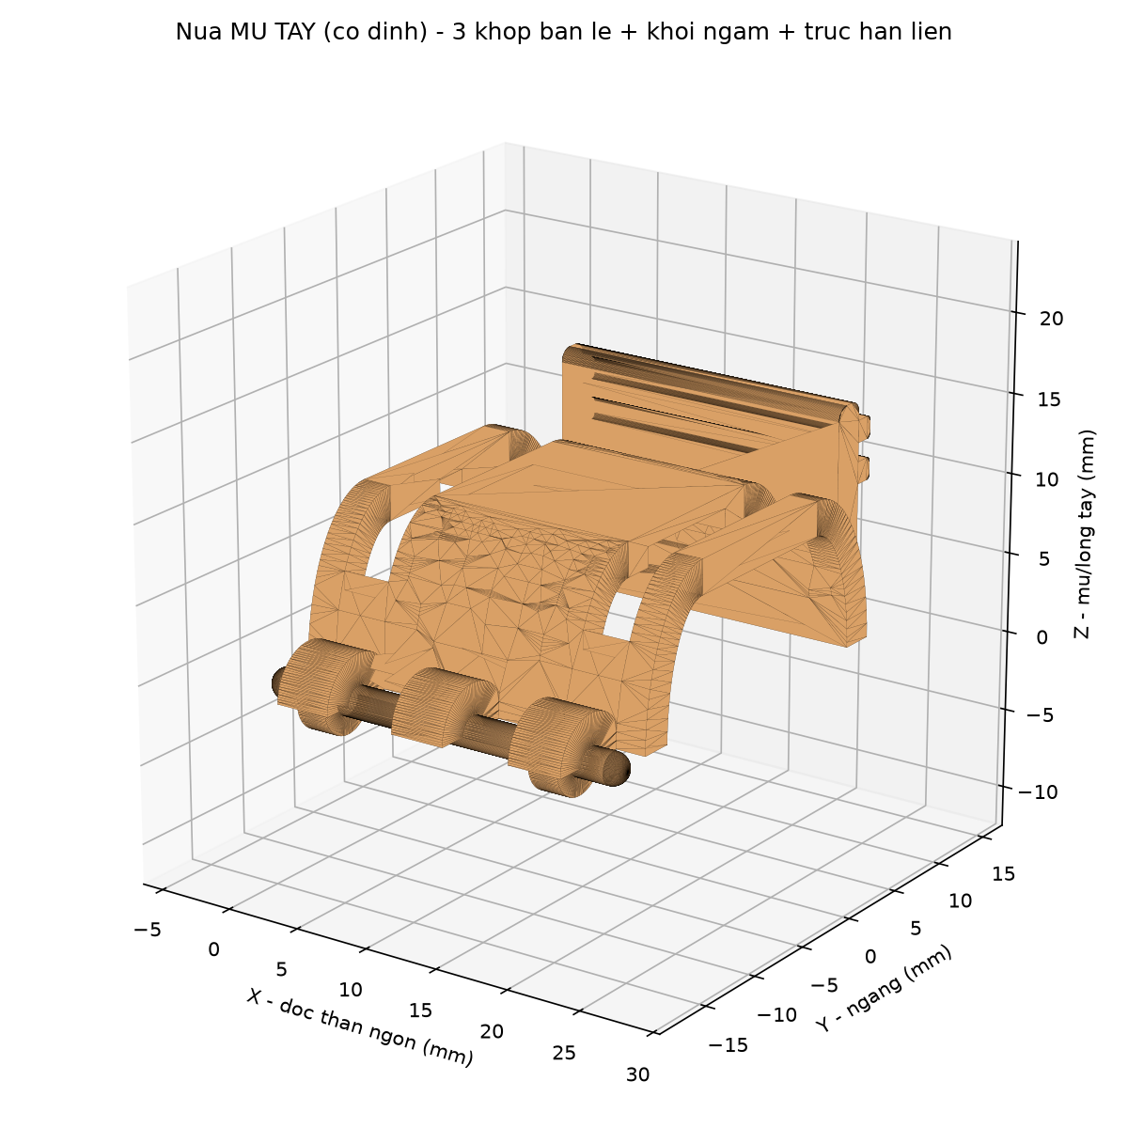
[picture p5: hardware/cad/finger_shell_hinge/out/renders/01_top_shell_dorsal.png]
top
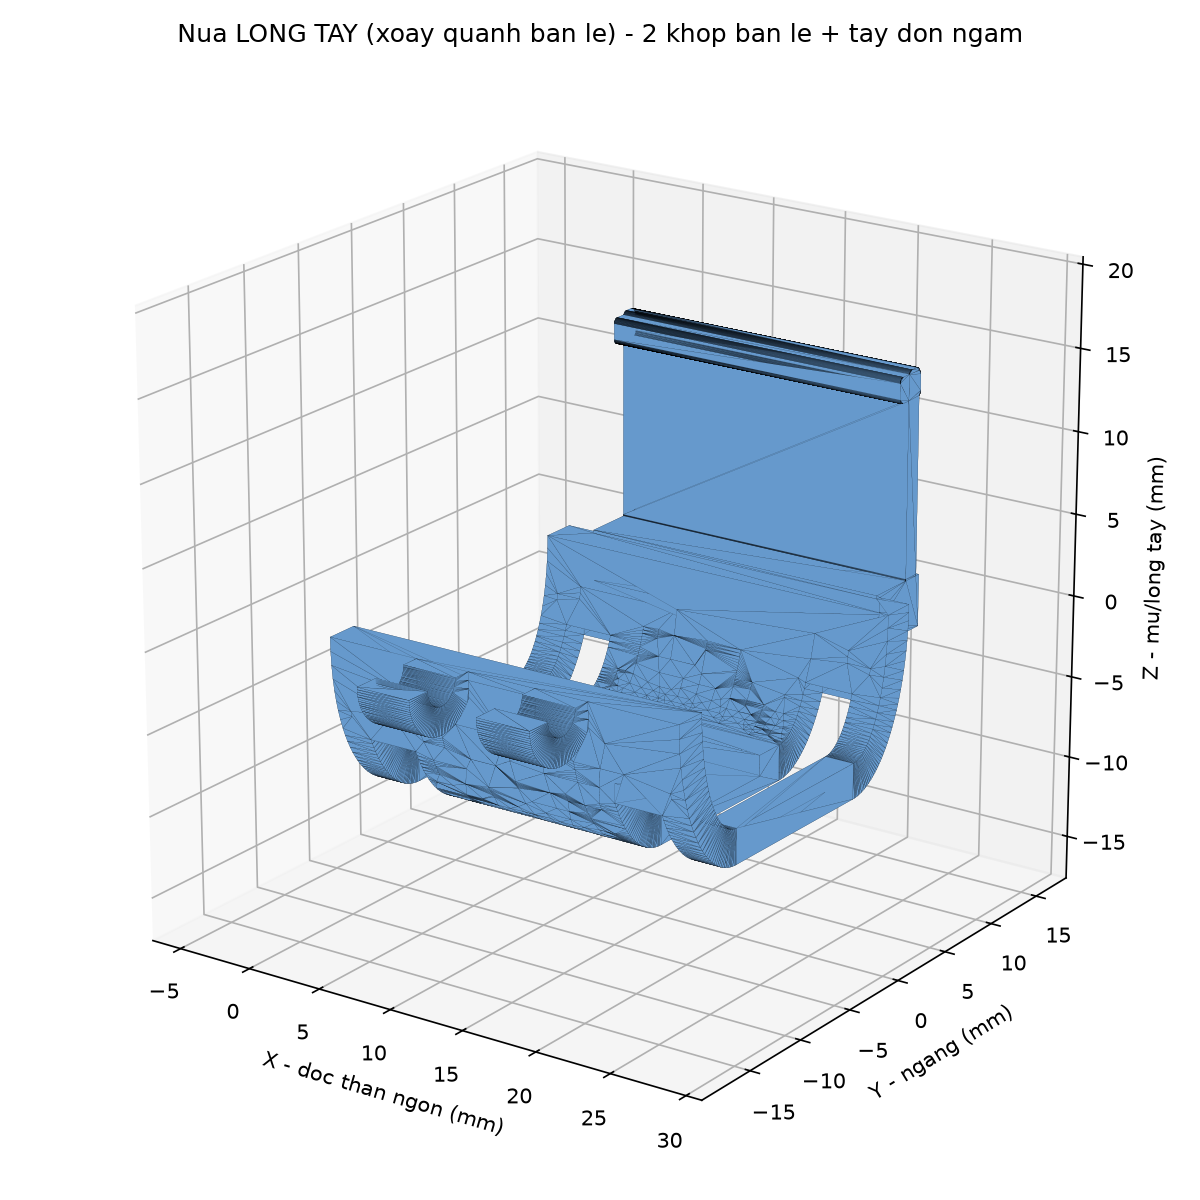
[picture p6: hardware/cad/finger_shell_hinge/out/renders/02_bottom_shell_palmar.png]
bottom
|  |  |

Chốt bản lề (chi tiết rời, không in liền khối với vỏ — xem lý do ở mục 5):

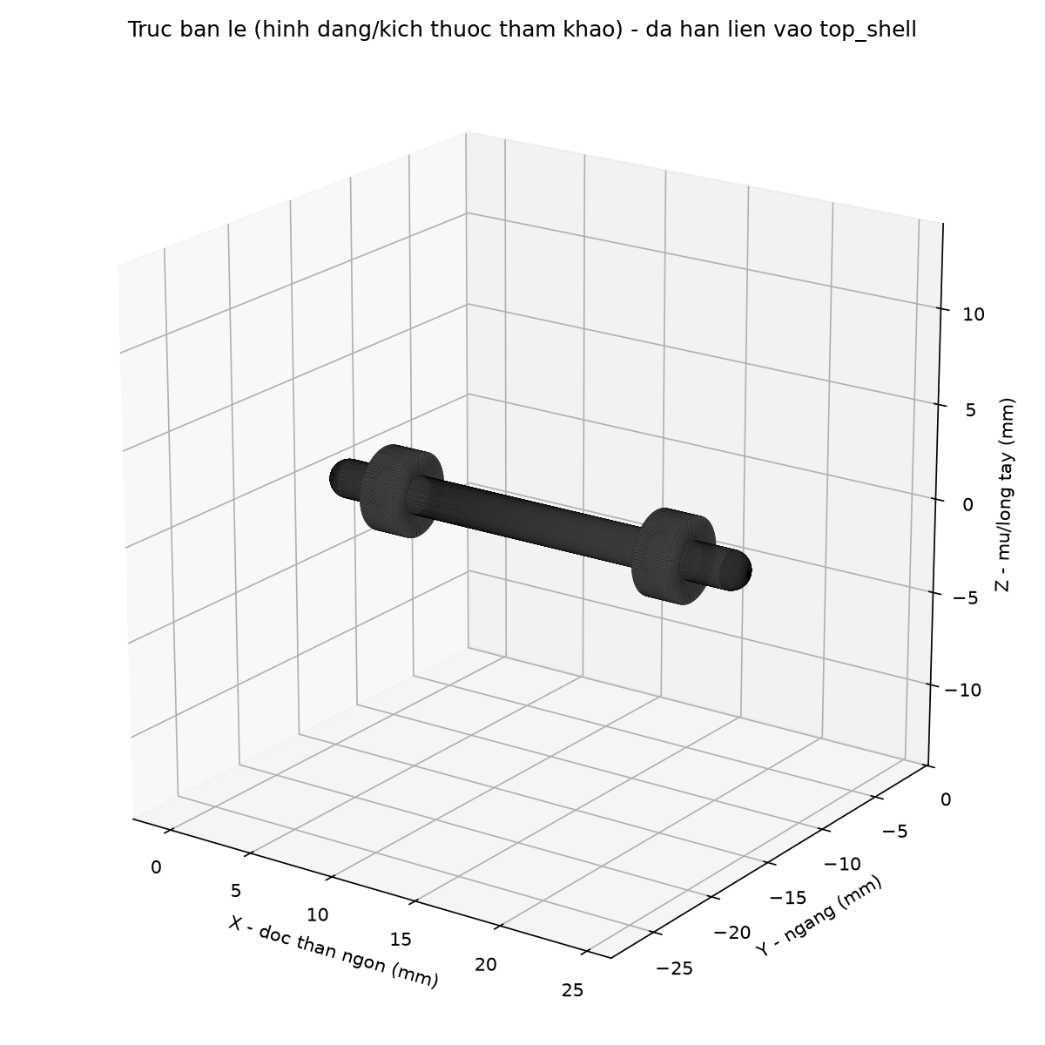
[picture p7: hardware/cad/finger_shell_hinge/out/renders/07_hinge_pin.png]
pin


**Vì sao không dùng "bản lề sống" (living hinge) in liền khối một mảnh?** Living hinge cần vật liệu dẻo dai khi gập mỏng (PP, hoặc TPU) và in rất mỏng (~0,6–1 mm) theo đúng hướng sợi; PETG/PLA — vật liệu đang dùng cho khung ốp (`docs/04` §6) — giòn hơn, living hinge bằng PETG/PLA dễ gãy sau vài chục lần gập/mở. Bản lề trục + chốt rời (kiểu "piano hinge") bền hơn khi in bằng PETG/PLA và cho phép thay chốt nếu mòn.

## 4. Thông số tham số hoá

Toàn bộ nằm trong class `P` ở đầu `finger_shell_hinge.py`. Các số dưới đây là **giá trị khởi tạo cho đốt gần (proximal phalanx) ngón trỏ/giữa người lớn, LẤY TẠM** — bắt buộc đo lại bằng thước cặp trước khi in bản dùng thật (nguyên tắc "ngân sách thiết kế, không phải kết quả đo" — `docs/04` đầu file).

| Tham số | Giá trị khởi tạo | Ý nghĩa |
|---|---|---|
| `L` | 24 mm | Chiều dài khung dọc ngón, đặt giữa thân đốt, tránh 2 khớp MCP/PIP |
| `W_in`, `H_in` | 19 mm, 16 mm | Kích thước trong (ngang × dày) quanh đốt ngón — **phải đo tay** |
| `t_wall` | 2.2 mm | Bề dày vách — PETG, ≥ 5 vòng tường (nozzle 0.4 mm) để cứng vững quanh hốc cảm biến |
| `flat_w` | 12 mm | **[2026-10-07, thay cho `r_in`/`r_out` cũ]** Bề rộng đoạn THẲNG ở giữa mặt mu/lòng tay (chỗ dán cảm biến) — 2 cạnh hông (bản lề + ngàm) bo tròn hết mức bằng cung elip lớn, xem §5d |
| `pocket_w/len/depth` | 8 / 16 / 1.3 mm | Hốc khoét để dán sandwich Velostat + đồng tự dính (theo `docs/04` §6) |
| `r_knuckle`, `r_pin` | 3.0 / 1.3 mm | Khớp ống bản lề (Ø ngoài 6 mm) và lỗ xỏ chốt/khớp xoay (Ø 2.6 mm) |
| `pin_clearance` | 0.3 mm | **[2026-10-07]** Khe hở BÁN KÍNH giữa trục đặc và lỗ — cho bản lề "in tại chỗ" (xem §5e), cần hiệu chỉnh theo máy in thật |
| `n_knuckle_top/bot` | 3 / 2 | Số khớp ống xen kẽ — **phải lệch nhau đúng 1** để xen kẽ đều (có `assert` trong code) |
| `catch_h`, `tooth_h`, `tooth_pitch` | 14 / 0.9 / 2.6 mm | Khối ngàm cố định, 2 nấc răng (preload thấp/cao) — `catch_h` tăng từ 9→14mm khi sửa lỗi lệch Z, xem §5c |
| `arm_h`, `arm_t`, `arm_hook` | 13 / 1.1 / 1.1 mm | Tay đòn đàn hồi + độ sâu móc |
| `strap_slot_w/h` | 3.2 / 6.0 mm | Khe luồn dây đai phụ (Velcro/thun) — khóa an toàn lớp 2 |

**Cách chỉnh preload (lực ép lên sensing element) ở bản v1 này:** thô, theo 2 nấc răng của ngàm (nấc 1 = ép nhẹ, nấc 2 = ép chặt hơn) — xem mục 8 "Giới hạn" về việc cần tinh chỉnh fine hơn (vít vi chỉnh) ở bản sau.

## 5. Môi trường dựng CAD (đã thử FreeCAD trước, không cài được trong sandbox này)

Theo đúng yêu cầu, đã thử cài FreeCAD trước. Trong môi trường chạy agent này **không có quyền truy cập kho `apt`/Debian** (chỉ cho phép ra ngoài tới GitHub/PyPI/npm), nên **không cài được gói `freecad` qua `apt`** và cũng không có GUI để chạy FreeCAD AppImage. Cũng đã thử tải thẳng **OpenSCAD AppImage** từ GitHub Releases — tải được trang `github.com` nhưng file nhị phân thật được GitHub chuyển hướng (redirect) sang `release-assets.githubusercontent.com`, domain này **không nằm trong danh sách host được phép ra ngoài** của sandbox.

**Giải pháp cuối cùng — 2 bản CAD song song, CẢ HAI đều đã chạy thật và ĐỐI CHIẾU chéo với nhau:**

1. **`finger_shell_hinge.py` (CadQuery → lõi hình học Open CASCADE, cùng lõi FreeCAD dùng bên trong):** cài qua `pip` (gói `cadquery-ocp` lấy OCCT dạng wheel từ PyPI, không cần `apt`). Gói này cần `libGL.so.1` lúc nạp module dù không render OpenGL thật, nên đã tạo một **thư viện giả (`stub`) `libGL.so.1`** bằng `gcc` (toàn hàm rỗng, chỉ để thoả mãn trình liên kết động). Dựng khối/boolean/fillet/xuất STEP/STL chạy trên lõi OCCT thật.
2. **`finger_shell_hinge.scad` (OpenSCAD → lõi hình học CGAL):** viết tay theo cú pháp OpenSCAD để bạn mở trực tiếp bằng app OpenSCAD miễn phí ([openscad.org](https://openscad.org/downloads.html)) trên máy mình, không cần Python. **Đã tìm được cách chạy CHÍNH ENGINE OPENSCAD ngay trong sandbox này** qua gói npm [`openscad-wasm-prebuilt`](https://www.npmjs.com/package/openscad-wasm-prebuilt) (bản WASM của OpenSCAD, chạy qua Node.js — `registry.npmjs.org` nằm trong danh sách host được phép) — xem `render_scad_wasm.mjs`. Đây là OpenSCAD **phiên bản 2025.01.19 thật**, không phải giả lập.

**Kết quả đối chiếu (`cross_check.py`, so thể tích + bounding-box của từng chi tiết xuất ra từ 2 lõi hình học độc lập — OCCT vs CGAL):**

| Chi tiết | Thể tích CadQuery/OCCT | Thể tích OpenSCAD/CGAL | Lệch | Bounding-box |
|---|---:|---:|---:|---|
| `top_shell_dorsal` | 2164.0 mm³ | 2161.8 mm³ | 0.10% | khớp tuyệt đối (25.0 × 32.06 × 15.0 mm) |
| `bottom_shell_palmar` | 1963.1 mm³ | 1961.1 mm³ | 0.10% | khớp tuyệt đối (24.0 × 33.10 × 23.2 mm) |
| `hinge_pin` | 76.4 mm³ | 76.2 mm³ | 0.27% | khớp tuyệt đối (25.0 × 2.0 × 2.0 mm) |

*(Số liệu trên là của bản mới nhất, 2026-10-07, sau khi sửa lỗi va chạm bản lề + đổi khe hở in-tại-chỗ — xem §5e. Số liệu sẽ còn thay đổi nhẹ mỗi khi chỉnh tham số hình học; chạy lại `cross_check.py` để lấy số mới nhất, đừng tin số cố định trong bảng này.)*

Sai số dưới 0,3% chỉ đến từ rời rạc hoá hình tròn (`$fn`), không phải sai lệch công thức. **Đây là bằng chứng độc lập (2 lõi CAD khác nhau — OCCT vs CGAL — cho cùng kết quả) rằng cả 2 file mô tả đúng cùng một hình học**, chứ **KHÔNG phải** bằng chứng thiết kế đã đúng về công thái học/cơ học — việc đó vẫn cần in thật + đo thật (mục 8).

**Dùng file `.scad` (khuyến nghị nếu bạn chỉ có máy cá nhân, không muốn cài Python):**

```bash
# 1. Cài OpenSCAD (Windows/macOS/Linux): https://openscad.org/downloads.html
# 2. Mở file:
openscad hardware/cad/finger_shell_hinge/finger_shell_hinge.scad
# 3. Trong OpenSCAD: Window > Customizer để chỉnh tham số bằng thanh trượt;
#    đổi biến PART ở cuối file ("top" | "bottom" | "pin" | "assembly_closed" | "assembly_open");
#    F5 = xem nhanh, F6 = render đầy đủ (bắt buộc trước khi xuất);
#    File > Export > Export as STL khi PART="top" hoặc "bottom" để lấy file in.
```

**Dùng file `.py` (CadQuery):**

```bash
python3 -m venv .venv && source .venv/bin/activate
pip install cadquery numpy-stl matplotlib
python3 hardware/cad/finger_shell_hinge/finger_shell_hinge.py   # xuất STEP/STL vào out/
python3 hardware/cad/finger_shell_hinge/render_preview.py       # xuất ảnh xem nhanh vào out/renders/
python3 hardware/cad/finger_shell_hinge/check_hinge_sweep.py    # [MỚI] quét va chạm bản lề qua cả dải góc mở — xem §5e
```

**Tự render `.scad` bằng engine OpenSCAD thật (qua Node.js, không cần cài OpenSCAD desktop) + tự đối chiếu:**

```bash
cd hardware/cad/finger_shell_hinge
npm install                 # cài openscad-wasm-prebuilt (~11MB, 1 gói)
node render_scad_wasm.mjs   # render ca 5 PART bang chinh OpenSCAD, xuat STL vao out/scad/
python3 cross_check.py      # so the tich + bounding-box voi out/*.stl (ban CadQuery)
```

(Nếu máy bạn thiếu `libGL.so.1` khi chạy bản CadQuery — ví dụ container tối giản — chỉ cần cài `libgl1` qua `apt` bình thường; sandbox này mới cần thủ thuật stub vì không có `apt`. Cách FreeCAD GUI thật nếu máy bạn có đủ mạng: `sudo apt-get install freecad && freecad hardware/cad/finger_shell_hinge/out/top_shell_dorsal.step`.)

## 5a. Lỗi đã sửa — tay đòn ngàm cài từng là 1 khối RỜI, không in được (2026-10-07)

**Người dùng phát hiện bằng mắt** khi tự mở `finger_shell_hinge.scad` bằng chính OpenSCAD trên máy mình: ở trạng thái "mở" (`assembly_open`), một mảnh phẳng nhỏ nổi lơ lửng tách rời hẳn khỏi phần vỏ chính — ảnh chụp cho thấy rõ khoảng trống giữa 2 khối.

**Kiểm chứng lại bằng số:** tay đòn ngàm cài (`latch_arm`, tay đòn đàn hồi gắn vào nửa lòng tay) được đặt ở toạ độ Y bắt đầu từ ~15.05mm (tâm) trong khi mép ngoài cùng của vỏ chỉ tới Y = W_out/2 ≈ 11.7mm — **lệch một khoảng trống ~2.8mm, không chạm vào vỏ ở bất kỳ lát cắt nào**. Dùng thư viện `trimesh` tách mảnh rời (`check_connectivity.py`) xác nhận: file STL `bottom_shell_palmar` (cả bản CadQuery lẫn bản OpenSCAD) bị tách thành **2 mảnh độc lập** — vỏ chính (~1660 mm³) và tay đòn+móc (~321 mm³) bay riêng, không hề dính vào nhau.

**Quan trọng:** đây là **lỗi thiết kế thật, tồn tại ở CẢ bản `.py` (CadQuery) VÀ bản `.scad` (OpenSCAD)** — không phải lỗi chuyển soạn từ file này sang file kia. Vì `cross_check.py` (mục 5) chỉ so khớp 2 bản **với nhau**, một lỗi giống hệt nhau ở cả 2 bản sẽ không bị phát hiện bằng cách đó — đây là lý do quan trọng để **luôn kiểm tra bằng mắt / bằng công cụ độc lập thứ 3**, không chỉ tin vào việc 2 bản khớp nhau.

**Đã sửa** (cả 2 file): thêm một **"gốc nối" (rib) đặc**, bắc cầu từ mép vỏ thật (lấn 0.3mm vào vỏ, giống cách khối răng `latch_catch` đã làm) tới mặt trong của tay đòn (lấn thêm 0.3mm vào tay đòn), nằm gọn trong vùng Z của nửa lòng tay (không đụng khối răng ở nửa mu tay). Đã chạy lại toàn bộ pipeline kiểm chứng sau khi sửa:

```
$ python3 check_connectivity.py
Nguon     File                          So manh roi   Ket qua
CadQuery  top_shell_dorsal.stl          1             OK (1 khoi lien)
CadQuery  bottom_shell_palmar.stl       1             OK (1 khoi lien)   <- truoc khi sua: 2
CadQuery  hinge_pin.stl                 1             OK (1 khoi lien)
OpenSCAD  top_shell_dorsal.stl          1             OK (1 khoi lien)
OpenSCAD  bottom_shell_palmar.stl       1             OK (1 khoi lien)   <- truoc khi sua: 2
OpenSCAD  hinge_pin.stl                 1             OK (1 khoi lien)
```

và `cross_check.py` vẫn PASS sau khi sửa (2 bản vẫn khớp nhau, lệch <0.3%). **`check_connectivity.py` đã được thêm làm bước kiểm tra bắt buộc** — chạy nó mỗi khi chỉnh sửa hình học, trước khi tin tưởng bất kỳ chi tiết nào in được nguyên khối.

Bài học: dù CAD đã "chạy được" (không lỗi CGAL/OCCT, bbox/thể tích đúng dự kiến), **không có nghĩa là hình học đó in được thành 1 khối** — vẫn cần kiểm tra tính liên kết (connectivity) riêng, vì phép hợp (`union`/`fuse`) của 2 khối không chạm nhau sẽ "thành công" về mặt code nhưng tạo ra 2 vật thể độc lập.

**Lỗi #2 (cùng ngày, cùng phiên phát hiện):** chủ dự án nhận ra ảnh lắp ráp (đóng/mở) **thiếu hẳn trục chốt bản lề** — 2 nửa vỏ có đủ khớp ống xen kẽ nhưng không có gì "xuyên qua" để giữ chúng lại, nhìn giống bản lề rỗng. Nguyên nhân: `export_assembly_state()` (.py) và `assembly_closed()`/`assembly_open()` (.scad) vốn chỉ vẽ 2 nửa vỏ, **quên vẽ `hinge_pin`/`build_pin()`** dù chi tiết chốt đã có sẵn trong file từ đầu (xuất riêng ra `hinge_pin.stl`). Đã sửa: thêm trục (màu xám đậm để phân biệt) vào cả 2 trạng thái lắp ráp ở cả 2 file; vì trục nằm đúng trên tâm trục xoay nên vị trí của nó không đổi giữa đóng/mở, không cần tính toán thêm.

## 5b. Thay đổi thiết kế theo yêu cầu — trục bản lề HÀN LIỀN vào nửa mu tay (2026-10-07)

**Yêu cầu của chủ dự án:** "cố định trục xám này với bản lề chính... khi in ra in nguyên 1 khối chứ không cần thay đổi" — tức muốn **bỏ việc chốt là 1 chi tiết rời phải lắp tay** (xỏ que/chốt qua lỗ sau khi in), thay vào đó **hàn trục liền vào nửa mu tay (bản lề cố định)** ngay từ lúc in.

**Đã làm** (tham số `PIN_INTEGRATED`, mặc định `true` ở cả 2 file):
- Nửa mu tay (`top_shell`) **không còn khoan lỗ chốt nữa** — thay vào đó, trục (đường kính giống hệt `hinge_pin.stl` trước đây) được **hợp nhất (`union`)** thẳng vào khối, nên `top_shell_dorsal.stl`/`.step` xuất ra **đã bao gồm sẵn trục**, in 1 lần duy nhất ra 1 khối liền (thể tích tăng từ ~2169mm³ lên ~2258mm³, đúng bằng thể tích trục ~78.5mm³ được cộng vào — đã kiểm chứng bằng `check_connectivity.py`: vẫn là 1 khối liền).
- Nửa lòng tay (`bottom_shell`) **vẫn luôn khoan lỗ** (khe hở bán kính 0.15mm) ở các khớp ống của nó — để có thể **trượt/xoay tự do quanh trục cố định** đã gắn liền vào nửa kia. Đây là phần BẮT BUỘC phải tách rời, vì nó cần di chuyển (mở ra/đóng vào) — không thể hàn liền với nửa mu tay.
- Lắp ráp: in 2 nửa riêng (mu tay đã có sẵn trục, lòng tay có lỗ trượt) → luồn khớp ống của nửa lòng tay vào dọc theo trục cố định từ một đầu (thao tác y hệt như trước, chỉ khác là không còn chi tiết chốt thứ 3 rời nữa).
- Vẫn giữ `PART = "pin"` và vẫn xuất `hinge_pin.stl` **chỉ để tham khảo kích thước trục** (không cần in riêng nữa ở chế độ mặc định).
- Muốn quay lại thiết kế cũ (chốt rời, có thể thay bằng que kim loại)? Đặt `PIN_INTEGRATED = False` (`.py`) hoặc `PIN_INTEGRATED = false;` (`.scad`, trong Customizer) rồi chạy lại.

**⚠️ Đánh đổi cần biết (không giấu):** mục 6 (hướng dẫn in) trước đây khuyến nghị **KHÔNG in chốt bằng nhựa** mà dùng que kim loại/nhựa cứng có sẵn (que hàn nhựa, đinh ghim, dây đồng Ø2mm) — lý do: một que nhựa mảnh (bán kính ~1mm) in bằng FDM dễ cong/gãy hơn vật liệu sẵn có, nhất là chịu lực uốn lặp lại của bản lề. **Khi hàn liền trục vào vỏ (`PIN_INTEGRATED=true`), ta mất luôn lựa chọn thay bằng que kim loại đó** — nếu trục in bị gãy trong lúc dùng, phải **in lại nguyên cả nửa mu tay**, không chỉ thay 1 que nhỏ như trước. Bù lại: ít chi tiết rời hơn (không lo mất chốt), lắp nhanh hơn (bớt 1 bước), và trục được 3 khớp ống "ôm" dọc suốt chiều dài nên có thể còn cứng vững hơn so với 1 que rời chỉ ăn khớp bằng ma sát. Đây là đánh đổi thiết kế, **chưa có số đo độ bền thật** — vẫn cần in thử + thử uốn/gập lặp lại trước khi kết luận cách nào bền hơn (xem mục 8).

## 5c. Lỗi đã sửa — móc và răng ngàm cài LỆCH NHAU 5-9mm, không bao giờ chạm được (2026-10-07)

**Bối cảnh:** chủ dự án yêu cầu "bo tròn đi bạn, rồi hoàn thiện, check lại cơ chế chính xác". Khi rà soát lại bằng tay toạ độ Z của từng nấc răng (`latch_catch`) so với toạ độ Z của móc (`latch_arm`, ở đầu tay đòn), phát hiện:

- Móc (hook) nằm ở Z = 11.20 – 12.80mm (công thức `arm_h - 1.0`, không đổi từ trước).
- Cả 2 nấc răng (cũ) nằm ở Z = 2.45 – 3.85mm và 5.05 – 6.45mm (công thức `catch_h * 0.35 + i*tooth_pitch`, tính **độc lập hoàn toàn** với công thức của móc).
- **Khoảng cách gần nhất giữa móc và răng gần nhất: ~4.75mm — không có bất kỳ điểm chồng lấn Z nào.** Theo trục Y thì 2 chi tiết có chồng lấn (Y = 13.55-14.86mm), nhưng vì Z hoàn toàn lệch nhau nên **móc không bao giờ chạm được răng khi gập xuống** — ngàm cài như cũ **không thể khóa được**, dù cả tay đòn lẫn khối ngàm đều "in được" bình thường (liền khối, đúng kích thước).

**Vì sao lỗi này không bị 2 công cụ kiểm tra trước đó bắt được:**
- `cross_check.py` chỉ so khớp bản `.py` và bản `.scad` **với nhau** — công thức lệch Z nói trên tồn tại **giống hệt ở cả 2 file** (cùng 1 nguyên nhân gốc: 2 công thức được viết độc lập, không tham chiếu chéo, trôi lệch nhau qua một lần sửa trước), nên so khớp 2 bản vẫn PASS.
- `check_connectivity.py` chỉ đếm số mảnh rời — răng và móc đều là một phần **liền khối** với vỏ chính của chúng (không rời ra thành mảnh riêng), nên cũng PASS.

Hai công cụ trên kiểm tra "chi tiết có in được không" (liền khối, đúng thể tích/kích thước) chứ **không kiểm tra "2 chi tiết có vai trò ăn khớp với nhau thì có thực sự giao nhau về hình học không"** — đây là một lớp lỗi khác, chỉ lộ ra khi **tính tay toạ độ cụ thể** của từng chi tiết rồi so sánh, đúng như yêu cầu "check lại cơ chế chính xác".

**Đã sửa** (cả 2 file): thay vì tính vị trí răng theo 1 tỉ lệ độc lập, giờ **tính trực tiếp từ vị trí nghỉ của móc** (`hook_rest_z = arm_h - 1.0`, cùng công thức dùng trong `latch_arm`), để 2 chi tiết **luôn thẳng hàng** dù sau này có đổi `arm_h`/`tooth_pitch`:
- Nấc 0: `z = hook_rest_z` (≈12.0mm) — nấc móc tự ăn khớp khi gập hẳn xuống.
- Nấc 1: `z = hook_rest_z - tooth_pitch` (≈9.4mm) — móc trượt qua nấc này trước khi tới vị trí nghỉ (cảm giác "tách" 2 nấc khi gập). **Lưu ý:** cách diễn giải "2 nấc = 2 mức khóa" là một giả thuyết cơ khí hợp lý nhưng **CHƯA được kiểm chứng bằng mẫu in thật** — chỉ xác nhận được bằng CAD rằng móc và nấc 0 giao nhau hình học ở trạng thái nghỉ.
- Tăng `catch_h` từ 9.0mm lên 14.0mm (đủ chứa nấc 0 ở Z≈12 cộng biên an toàn), và thêm `assert(catch_h >= hook_rest_z + 1.5, ...)` ở cả 2 file để lần sau nếu ai đổi `arm_h`/`catch_h` mà quên cập nhật, CAD sẽ **báo lỗi ngay khi dựng hình** thay vì âm thầm sinh ra 1 ngàm không khóa được như lần này.

**Kiểm chứng bằng số liệu, lấy TRỰC TIẾP từ mã nguồn** (không phải tính tay/giả định — xem `check_latch_engagement.py`, công cụ kiểm tra mới thêm):

```
$ python3 check_latch_engagement.py
Moc (hook):  X=2.00..22.00  Y=13.55..15.75  Z=11.20..12.80
Nac rang 0: ... Y=13.06..14.86  Z=11.30..12.70  | chong lan Y=1.31mm Z=1.40mm -> AN KHOP
Nac rang 1: ... Y=13.06..14.86  Z=8.70..10.10   | chong lan Y=1.31mm Z=0.00mm -> khong giao nhau
KET LUAN: OK -- moc va it nhat 1 nac rang CO giao nhau hinh hoc ...
```

`cross_check.py` và `check_connectivity.py` vẫn PASS sau khi sửa (không có hồi quy — xem lệnh chạy ở §5a/§5b, kết quả tương tự).

**`check_latch_engagement.py` đã được thêm làm bước kiểm tra bắt buộc thứ 3** (bên cạnh `cross_check.py` và `check_connectivity.py`) — dùng cho bất kỳ 2 chi tiết nào có vai trò ăn khớp cơ học với nhau (không chỉ ngàm cài), để bắt đúng lớp lỗi "liền khối + đúng kích thước nhưng không tương tác được với nhau" mà 2 công cụ kia không bắt được.

**Giới hạn tự khai:** script chỉ kiểm tra bounding-box có giao nhau ở **trạng thái nghỉ tĩnh** (điều kiện CẦN để khóa được) — **không** mô phỏng lực cài, độ đàn hồi thực tế của tay đòn PETG mỏng (`arm_t=1.1mm`), hay đường đi 3D thực sự của móc khi xoay quanh bản lề (kiểm tra này giả định móc tiếp cận "thẳng xuống", trong khi thực tế là một cung xoay quanh trục bản lề ở xa). Đây **vẫn là thiết kế trên giấy, chưa in thử** — lực cài/mở, độ bền mỏi của tay đòn, và cảm giác "clic" 2 nấc vẫn cần xác nhận bằng mẫu in thật (xem mục 8).

### Bo tròn các cạnh (cùng yêu cầu "bo tròn đi bạn, rồi hoàn thiện")

Ngoài việc sửa lỗi lệch Z ở trên, đã bo tròn thêm các chi tiết sau (cả 2 file), chủ yếu để giảm cạnh sắc (an toàn khi tiếp xúc với tay người chăm sóc/bệnh nhân khi thao tác, giảm tập trung ứng suất khi in FDM) và cho cảm giác "hoàn thiện" hơn một bản thiết kế thô ráp:

- **2 đầu trục bản lề (hinge_pin):** trước đây là hình trụ cắt vuông (2 mặt phẳng tròn, cạnh sắc); giờ là "viên nang" (capsule) — 2 đầu bo tròn thành chỏm bán cầu. Giúp đầu trục dễ dùng làm mồi luồn qua các khớp ống khi lắp ráp, và an toàn hơn ở 2 đầu lộ ra ngoài.
- **Khối ngàm chính (`latch_catch`) và 2 nấc răng:** bo nhẹ các cạnh dọc theo chiều dài ngón tay (bán kính 0.3-0.8mm tuỳ bề dày từng chi tiết, luôn chọn nhỏ hơn 1 nửa bề dày mỏng nhất để không làm biến dạng/triệt tiêu chi tiết).
- **Thân tay đòn (`latch_arm`) và móc:** bo nhẹ tương tự (bán kính 0.3mm, nhỏ vì `arm_t`/`arm_hook` khá mỏng ~1.1mm) — **riêng "gốc nối" (root/rib) ở chân tay đòn CỐ Ý giữ cạnh vuông sắc**, không bo tròn, để không ảnh hưởng tới vùng tiếp xúc quan trọng với vỏ đã sửa lỗi liền khối ở §5a (đã xác nhận lại bằng `check_connectivity.py` sau khi bo — vẫn 1 khối liền, không hồi quy).
- **Chưa bo tròn:** mép hở 2 đầu ống (nơi tiết diện ống tròn-bo-góc gặp 2 mặt phẳng đầu ống thẳng, tại X=0 và X=L) — đây là nơi tiếp xúc trực tiếp với da nhiều nhất nên về lý thuyết cũng nên bo, nhưng việc bo tròn đầy đủ 3D ở đây đòi hỏi kỹ thuật dựng hình phức tạp hơn nhiều (có nguy cơ làm mỏng thành ống ở đúng đầu mút nếu làm không cẩn thận) — **cố tình hoãn lại**, ưu tiên sự chắc chắn/an toàn của hình học hơn là làm nhanh cho đẹp. Nếu chủ dự án muốn, đây sẽ là việc cần làm ở vòng sau.

**Lưu ý kỹ thuật khi dựng bằng OpenSCAD:** ban đầu dùng `hull()` của 2 hình cầu để tạo "viên nang" cho trục — dựng ĐƯỢC từng chi tiết riêng lẻ, nhưng khi `union()` vào toàn bộ lắp ráp phức tạp (`top_shell`) thì CGAL (bộ dựng hình của OpenSCAD) báo lỗi nội bộ ("assertion violation") và ÂM THẦM cắt mất ~0.5mm ở mỗi đầu trục (không crash, không báo lỗi ra STL, chỉ lộ ra khi so bounding-box với bản CadQuery bằng `cross_check.py`). Đã đổi sang dựng "viên nang" bằng `union()` của 1 hình trụ ngắn hơn + 2 chỏm cầu (hình dạng giống hệt, nhưng ổn định hơn với CGAL) — sau khi đổi, `cross_check.py` khớp lại hoàn toàn (<0.1% lệch thể tích, bbox khớp đến 0.003mm). Đây là một ví dụ cụ thể cho thấy **"không có lỗi CGAL/không crash" không đồng nghĩa với "hình học đúng như ý đồ"** — bài học tương tự mục 5a, lần này ở công cụ OpenSCAD thay vì CadQuery.

## 5d. Thay đổi thiết kế theo yêu cầu — tiết diện "hình trụ" thay cho hộp chữ nhật bo góc (2026-10-07)

**Phản hồi của chủ dự án** sau khi xem ảnh trạng thái đóng: tiết diện hộp chữ nhật bo góc nhìn "vuông, cứng ngắc", đề nghị đổi sang dáng tròn/hình trụ hơn.

**Làm rõ trước khi sửa:** ngón tay thật có tiết diện hơi bầu dục (rộng hơn dày — `W_in=19mm` x `H_in=16mm`), và 2 cạnh hông của khung cần có **mặt tương đối phẳng** để gắn 3 khớp bản lề + khối ngàm cài, còn 2 mặt mu/lòng tay cần **mặt phẳng** để dán hốc cảm biến Velostat+đồng (`pocket_w=8mm`). Một hình trụ tròn thật (1 đường kính duy nhất, không còn phân biệt rộng/dày) sẽ cần thêm "mấu" phẳng nhô ra mới gắn được bản lề/ngàm — thay đổi lớn hơn, nên đã hỏi lại chủ dự án và chọn phương án: **bo tròn hết mức có thể ở 2 cạnh hông, giữ nguyên 2 mặt mu/lòng tay phẳng**.

**Đã làm** (cả 2 file, hàm `rounded_prism()`/`capsule_prism()` dựng lại từ đầu):
- Bỏ hẳn cách bo góc chữ nhật kiểu cũ (`r_in=2.5mm`, `r_out=4.0mm` — góc bo nhỏ so với kích thước tổng, nhìn "vuông, cứng ngắc" như chủ dự án nhận xét).
- Tiết diện mới là 1 lăng trụ **"viên thuốc dẹt" (capsule)**: 2 mặt mu tay/lòng tay chỉ còn 1 đoạn **THẲNG** ở giữa rộng `flat_w=12mm` (đủ chứa hốc cảm biến 8mm + biên 2mm mỗi bên) — đủ để dán phẳng cảm biến/luồn dây đai. Toàn bộ phần còn lại của tiết diện, **kể cả 2 cạnh hông**, là 1 đường cong elip LIÊN TỤC nối tiếp tuyến (không góc gãy) với 2 đầu đoạn thẳng: với `W_out=23.4mm`, `H_out=20.4mm`, bán trục elip theo chiều rộng `a = W_out/2 - flat_w/2 = 5.7mm`, theo chiều dày `b = H_out/2 = 10.2mm`. Nói cách khác, cạnh hông không còn là góc bo nhỏ rời rạc như trước mà là 1 nửa elip trơn chạy suốt từ mép trên xuống mép dưới — không còn đoạn thẳng dọc hay góc vuông nào ở đó.
- Giới hạn hình học còn lại: đoạn thẳng `flat_w=12mm` ở mặt mu/lòng tay là bắt buộc phải giữ (chứa hốc cảm biến 8mm + biên 2mm mỗi bên); nếu giảm `flat_w` về gần 0 để tiến tới hình trụ/elip tròn tuyệt đối trên toàn tiết diện thì sẽ không còn đủ mặt phẳng để khoét hốc cảm biến — đây là lý do dừng ở `flat_w=12mm` thay vì bỏ hẳn mặt phẳng.
- **Đã kiểm tra độ dày thành còn lại** (giữa mặt ngoài và mặt trong, dọc theo cung elip, tính bằng toạ độ tham số — không phải đo trên mẫu in thật): mỏng nhất ≈ 2.08mm (tại góc ~52° so với mặt phẳng ngang), so với `t_wall=2.2mm` danh định — giảm ~6%, vẫn an toàn cho PETG 5 vòng tường 0.4mm. Vùng mặt phẳng (nơi hốc cảm biến) và vùng xích đạo cạnh hông (nơi gắn khớp bản lề) đều giữ đúng `t_wall=2.2mm`.
- **Bản lề và ngàm cài không cần sửa gì** — công thức gắn khớp ống (`add_hinge_knuckles`, tại `z=0`, `y=±W_out/2`) và gốc nối ngàm (`add_latch_catch`/`add_latch_arm`, cũng neo tại `y=±W_out/2`) đều dùng đúng điểm "xích đạo" của tiết diện mới, vị trí không đổi so với tiết diện cũ (elip tại z=0 vẫn chạm đúng y=±W_out/2, giống hệt hình chữ nhật bo góc cũ tại z=0) — đã xác nhận lại bằng `check_latch_engagement.py` và `check_connectivity.py`, không có hồi quy.

**Kiểm chứng:** `cross_check.py` khớp lại hoàn toàn giữa bản `.py` (CadQuery, dùng `ellipseArc()`) và bản `.scad` (OpenSCAD, dùng `polygon()` lấy mẫu 16 điểm/góc phần tư qua hàm số) — lệch thể tích 0.11-0.27% (chỉ do rời rạc hoá góc, OpenSCAD dùng đa giác xấp xỉ còn CadQuery dùng cung elip thật mượt của OpenCASCADE). `check_connectivity.py` và `check_latch_engagement.py` đều PASS, không hồi quy so với §5c.

**Giới hạn tự khai:** độ dày thành mỏng nhất (2.08mm) chỉ tính bằng công thức hình học (khoảng cách Euclid giữa 2 đường cong tham số hoá cùng góc — xấp xỉ, không phải khoảng cách pháp tuyến chính xác tuyệt đối), **chưa đo trên mẫu in thật** và chưa có phân tích độ bền cơ học (FEA) cho vùng thành cong mỏng hơn này so với bản chữ nhật cũ. Cảm giác "tròn trịa, bớt cứng ngắc" mới chỉ được xác nhận qua ảnh CAD (`out/renders/`), chưa xác nhận bằng cách cầm/sờ mẫu in thật.

## 5e. LỖI NGHIÊM TRỌNG đã sửa — 2 nửa vỏ ĐÂM XUYÊN NHAU khi mở + đổi sang bản lề "in tại chỗ" (2026-10-07)

**Yêu cầu chủ dự án** (nguyên văn ý): bản lề chỉ cần 1 nửa chứa sẵn trục, nửa kia được in BỌC QUANH trục đó ngay trong lúc in (không lắp tay), rồi khi lấy ra khỏi máy in là xoay được tự do quanh trục tại chỗ.

### Phần 1 — lỗi nghiêm trọng phát hiện khi kiểm tra lại yêu cầu này

Để trả lời đúng câu "xoay có tự do không", **lần đầu tiên bản vẽ này được quét kiểm tra va chạm hình học qua TOÀN BỘ dải góc mở** (trước đây chỉ xem bằng mắt ở ĐÚNG 1 góc cuối, 150°, qua ảnh `05_assembly_open_iso.png`). Dùng `top.intersect(bottom_xoay_tung_goc)` của CadQuery (phép giao boolean thật trên lõi OCCT, không phải ước lượng), phát hiện: **với dấu góc xoay cũ (+150°), 2 nửa vỏ THẬT SỰ ĐÂM XUYÊN NHAU** — thể tích giao nhau lên tới **~600mm³** (so với tổng thể tích 1 nửa ~2000mm³, tức là xuyên **30%** khối lượng) trong suốt khoảng góc **+5° đến +100°**. Ảnh chụp 2 khối ở +45° cho thấy rõ khối xanh (lòng tay) cắm thẳng vào khối cam (mu tay):

- Hướng SAI (+45°): nửa lòng tay xuyên qua nửa mu tay — xem bằng chứng quét (bảng dưới).
- Hướng ĐÚNG (-45°): 2 nửa tách rời sạch sẽ.

Nguyên nhân: trục bản lề được đặt lệch ra ngoài mép vỏ (để chừa chỗ cho khớp ống) nhưng **dấu chiều xoay (sign) bị chọn SAI** — xoay theo chiều đó khiến điểm xa trục nhất của nửa lòng tay (mép đối diện, phía ngàm cài) quét một cung đi THẲNG vào khối đặc của nửa mu tay trước khi ra khỏi vùng va chạm (chỉ "tình cờ" sạch trở lại ở đúng góc 150°, là góc duy nhất có ảnh render trước đây). Đây là lý do việc chỉ xem 1 ảnh tĩnh ở góc cuối **không đủ** để xác nhận "bản lề xoay được" — phải quét liên tục.

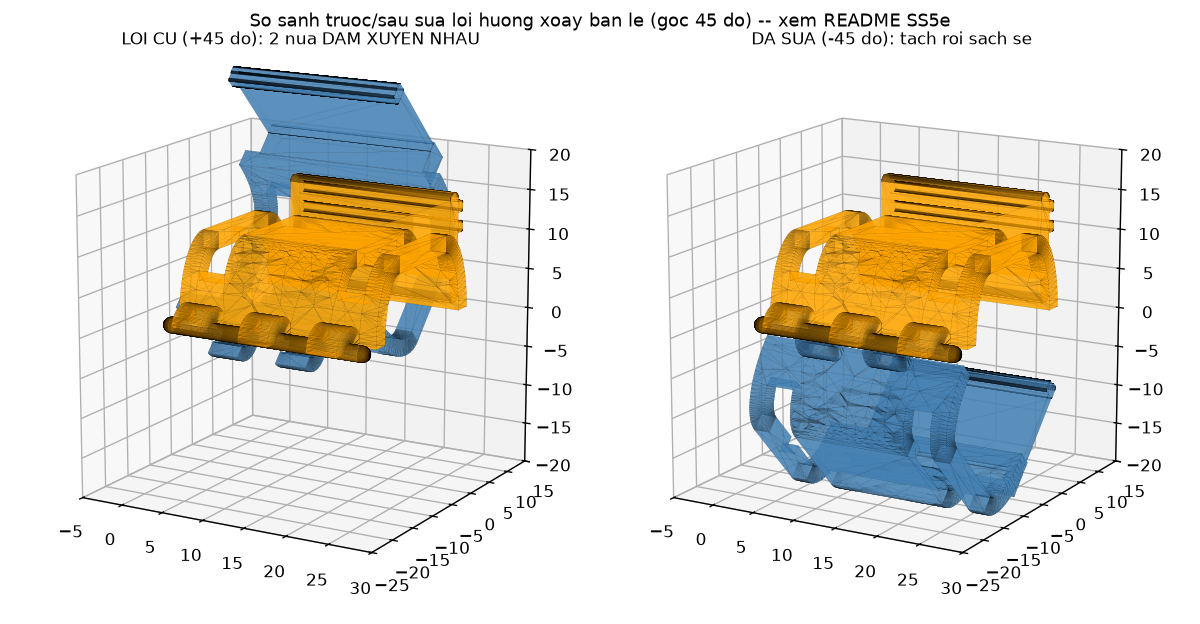
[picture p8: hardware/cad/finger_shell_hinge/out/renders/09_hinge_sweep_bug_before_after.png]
so sanh loi huong xoay truoc/sau sua

*Trái: dấu góc xoay CŨ (+45°) — khối xanh (lòng tay) cắm xuyên qua khối cam (mu tay). Phải: dấu ĐÃ SỬA (-45°) — 2 nửa tách rời sạch sẽ.*

**Đã sửa:** đổi dấu góc xoay trong `build_open_bottom_shell()` (`.py`) và `assembly_open()` (`.scad`) từ dương sang âm. **Đã thêm công cụ kiểm tra thường trực mới — `check_hinge_sweep.py`** — quét giao nhau mỗi 5° từ 0° đến 150°, FAIL nếu bất kỳ góc nào (ngoài vùng ngàm cài đang nhả ra ở 0-10°, nơi có chồng lấn nhỏ CỐ Ý do móc còn trượt qua răng) có giao nhau > 0.05mm³. Sau khi sửa: **0.0mm³ giao nhau ở MỌI góc từ 15° đến 145°, và chỉ 0.02mm³ (không đáng kể) ở 150°** — bằng chứng hình học rằng bản lề xoay tự do suốt hành trình, không chỉ ở điểm cuối.

**Đồng thời sửa luôn 1 lỗi nhỏ liên quan** phát hiện cùng lúc: khớp ống (knuckle) trước đây là hình trụ tròn ĐỦ, tâm đúng tại mặt phân 2 nửa (Z=0), nên một nửa khối của nó luôn "tràn" sang phía nửa kia — gây chồng lấn ~9.4mm³ không đổi theo góc xoay (vì nằm sát trục, không di chuyển khi quay). Đã cắt khớp ống về đúng nửa không gian của chính nó (`half_space()`/`intersection()`) trước khi union vào vỏ — chồng lấn này nay bằng 0.

**Giới hạn tự khai:** đây là bằng chứng HÌNH HỌC (2 khối CỨNG không đâm xuyên nhau), KHÔNG phải bằng chứng cơ học thật — ma sát, độ đàn hồi PETG, dung sai in thật (khớp ống không tròn hoàn hảo, co ngót vật liệu) có thể khiến bản lề thật bị kẹt dù mô hình CAD không báo lỗi. Việc phát hiện lỗi lớn này ở vòng kiểm tra trước (vốn đã công bố renders "đã xác nhận trực quan") cũng là lời nhắc: **kiểm tra bằng ảnh tĩnh 1 góc là KHÔNG ĐỦ** cho các cơ cấu chuyển động — từ nay `check_hinge_sweep.py` chạy mỗi khi đổi tham số hình học liên quan đến bản lề.

### Phần 2 — bản lề "in tại chỗ" (print-in-place) theo đúng yêu cầu

Thiết kế từ trước (§5b) đã có phần: `top_shell` hàn liền (union) trục bản lề đặc vào thân — khi `PIN_INTEGRATED=True` (mặc định). Phần còn thiếu để thành bản lề in-tại-chỗ đúng nghĩa là: (a) khe hở trục-lỗ đủ rộng để máy in FDM không làm dính liền 2 khối, và (b) một file in gộp cả 2 nửa làm 1 lần in.

- **Khe hở (`pin_clearance`):** trước đây là số viết tay 0.15mm bán kính (0.3mm đường kính) ngay trong code — theo các nguồn hướng dẫn thiết kế bản lề in-tại-chỗ FDM ([Snapmaker](https://www.snapmaker.com/blog/3d-printed-hinges/), [FastPreci](https://www.fastpreci.com/blog/3d-printed-hinges/), [QIDI 3D](https://qidi3d.com/blogs/news/how-to-3d-print-interlocking-parts-and-assemblies)), khoảng khuyến nghị phổ biến cho khớp quay in-tại-chỗ là **0.2-0.4mm bán kính** (0.15mm dễ bị dính liền nếu máy chưa hiệu chỉnh hoàn hảo, nhất là do "chân voi" lớp đầu). Đã tăng lên **0.3mm** (tham số `pin_clearance`, đặt tên rõ ràng thay vì số viết tay) và tăng `r_pin` (lỗ) từ 1.15mm lên 1.3mm để GIỮ NGUYÊN bán kính trục đặc ~1.0mm (không đổi độ cứng trục) mà vẫn đạt khe hở mới.
- **File in gộp:** hàm mới `export_print_in_place()` (`.py`) xuất **1 file STL duy nhất** (`out/assembly_open_print_in_place.stl`) chứa cả `top_shell` (đã có trục) và `bottom_shell` ở **trạng thái MỞ** (2 solid riêng biệt, không boolean-union, chỉ cách nhau đúng khe hở) — nạp thẳng file này vào slicer là in được cả 2 nửa cùng lúc, lấy ra là xoay ngay, không cần lắp. Bản `.scad` tương đương là `out/scad/assembly_open.stl` (đã xuất sẵn qua `render_scad_wasm.mjs`).
- **QUAN TRỌNG — vì sao là trạng thái MỞ chứ không phải ĐÓNG:** ở trạng thái ĐÓNG, ngàm cài (móc + răng) CỐ Ý chạm/ngoàm vào nhau (giao nhau ~51.5mm³ — đây là độ ngoàm cần thiết để khoá chặt, xem §5c) — nếu xuất file in gộp ở tư thế này, slicer sẽ in LIỀN 2 chi tiết ngàm cài thành 1 khối đặc dính nhau tại đúng chỗ ngoàm (không giống bản lề, chỗ này KHÔNG có khe hở), làm tay đòn đàn hồi mất khả năng bật ra — hỏng ngàm cài vĩnh viễn. Ở trạng thái MỞ (150°), ngàm cài tách xa nhau hẳn, nên an toàn để in gộp; **sau khi in xong, gập tay bằng tay để đóng + cài ngàm** như quy trình sử dụng vốn có.
- **Đã kiểm tra:** `assembly_open_print_in_place.stl` (`.py`) được load lại bằng `trimesh`, tách được đúng **2 thành phần kín nước (watertight) riêng biệt**, thể tích khớp với `top_shell`/`bottom_shell` xuất riêng (chênh < 0.1%) — xác nhận file là 2 khối thật sự tách rời (không bị dính), sẵn sàng để thử in. File `.scad` tương ứng (`out/scad/assembly_open.stl`) qua kiểm tra tương tự ra 1 mảnh kín nước duy nhất (OpenSCAD CSG `union()` hợp nhất 2 khối chạm/gần chạm thành 1 mesh — khác cách biểu diễn với bản `.py` nhưng cùng ý nghĩa: không có chỗ nào chồng lấn thể tích đáng kể ngoài dự kiến).

**Giới hạn tự khai (QUAN TRỌNG — chưa in thật):** khe hở 0.3mm là **điểm khởi đầu phổ biến theo tài liệu hướng dẫn chung**, KHÔNG phải số đã hiệu chỉnh cho máy in/vật liệu cụ thể nào — từng máy in (độ chính xác cơ khí, hiệu chỉnh dòng nhựa/flow, "chân voi" lớp đầu) có thể cần tăng/giảm. Khuyến nghị in thử 1 bản lề nhỏ (chỉ đoạn có khớp ống, vài cm) với 3-4 mức khe hở (0.2/0.25/0.3/0.35mm) trước khi in bản đầy đủ, theo đúng tinh thần "ngân sách thiết kế, không phải kết quả đo" của `docs/04`. Việc bản lề "xoay được trên CAD" (hình học) KHÔNG đảm bảo "xoay được khi in" (vật lý) — vẫn cần thử nghiệm in thật.

## 5f. LỖI đã sửa — trục bản lề KHÔNG CÓ gì chặn, nửa lòng tay có thể TUỘT dọc trục ra ngoài (2026-10-08)

**Yêu cầu chủ dự án:** kiểm chứng lại bản lề đủ 3 điều: (1) xoay tự do quanh trục, (2) không có lỗi, (3) **không dễ rơi/tuột ra ngoài**. (1) và (2) đã có bằng chứng từ §5e (`check_hinge_sweep.py`), nhưng (3) là một yêu cầu MỚI — khi kiểm tra lại, phát hiện đây KHÔNG CHỈ là một quan ngại giả thuyết mà là **một lỗi hình học thật sự chưa từng được kiểm tra**.

**Lỗi phát hiện:** `check_hinge_sweep.py` (§5e) chỉ quét **góc xoay**, chưa bao giờ quét **chuyển vị dọc trục** (translate dọc theo trục X của bản lề). Khi xem lại `build_pin()`, trục bản lề là một hình trụ **bán kính không đổi suốt chiều dài** (chỉ bo tròn 2 đầu thành chỏm bán cầu) — **không có vai/mũ/gờ nào rộng hơn lỗ khớp ống** ở bất kỳ đâu dọc trục. Vì 2 khớp ống của nửa lòng tay là 1 khối cứng duy nhất (di chuyển cùng nhau), **không có gì về mặt hình học ngăn cả nửa lòng tay trượt dọc theo trục và tuột hẳn ra khỏi 1 trong 2 đầu trục** — một rủi ro thật khi thao tác, tháo/lắp lên tay bệnh nhân, hoặc rung lắc khi dùng.

**Đã sửa:** thêm **2 "vai chặn" hình TRỤ ĐỒNG TRỤC** (collar, bán kính `pin_retain_r = 2.2mm`, dài `pin_retain_len = 2.0mm`) hàn liền vào trục, đặt đúng **tâm của khớp ống ĐẦU và CUỐI** thuộc nửa mu tay. Vì bán kính vai chặn (2.2mm) lớn hơn hẳn bán kính lỗ khớp ống của nửa lòng tay (`r_pin = 1.3mm`), và mọi khớp ống của nửa lòng tay đều nằm **giữa** 2 vai chặn này theo trục X, nửa lòng tay **không thể trượt dọc trục qua khỏi vai chặn mà không đâm xuyên vật liệu thật** — chặn được cả 2 hướng tuột. *(Xem đính chính 2026-10-08 ở cuối mục này: câu "ẩn gọn, không tạo gờ nhô mới" viết ban đầu ở đây KHÔNG CHÍNH XÁC — đã đo lại và sửa.)*

*Vì sao dùng hình TRỤ chứ không phải hình CẦU (phương án thử đầu tiên):* hình cầu tạo ra 1 điểm cực (pole) kỳ dị về mặt tham số hoá bề mặt — khi xuất STL, lưới tam giác hoá tại điểm cực này sinh ra 1 tam giác thể tích gần-bằng-0 bị `check_connectivity.py` báo nhầm là "mảnh rời" (artefact dựng lưới, không phải lỗi hình học thật — đã xác nhận bằng `.clean()` không giải quyết được). Đổi sang hình trụ **đồng trục với chính trục bản lề** thì không còn điểm kỳ dị nào — hết lỗi mảnh rời ngay, xác nhận lại bằng `check_connectivity.py` (PASS, 1 khối liền cho cả `.py` và `.scad`).

**Công cụ kiểm tra mới — `check_axial_retention.py`:** quét chuyển vị dọc trục X từ 0 đến ±25mm, tính thể tích giao nhau (boolean intersection) thật giữa `bottom_shell` đã dịch chuyển và trục (`build_pin()`), ở CẢ 2 phiên bản trục (cũ: không vai chặn / mới: có vai chặn) để làm đối chứng trước/sau:

| Hướng trượt | Trục CŨ (không vai chặn) | Trục MỚI (có vai chặn) |
|---|---|---|
| +X | 0.0 mm³ ở MỌI bước quét — **không chặn gì cả** | tới **9.90 mm³** giao nhau trước khi qua được — **bị chặn thật** |
| −X | 0.0 mm³ ở MỌI bước quét — **không chặn gì cả** | tới **9.90 mm³** giao nhau trước khi qua được — **bị chặn thật** |

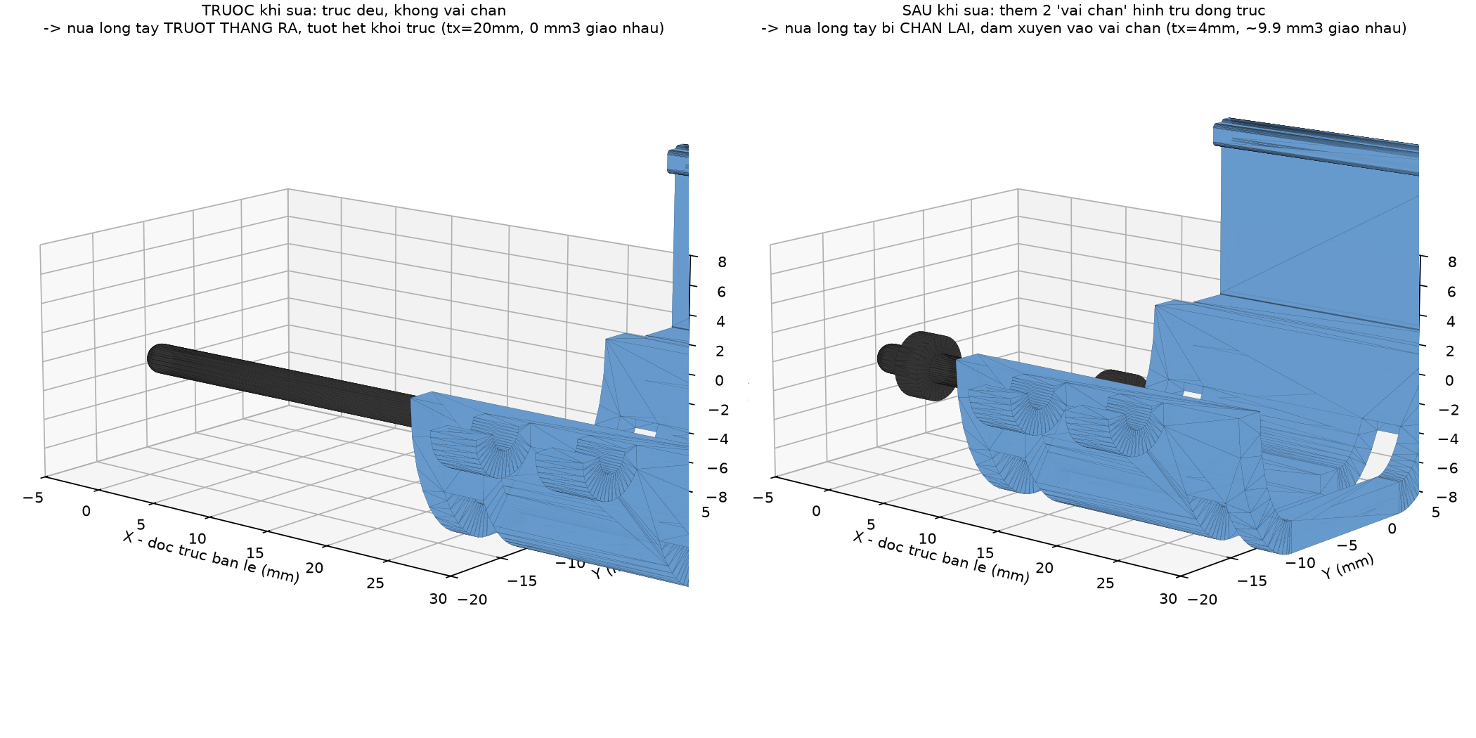
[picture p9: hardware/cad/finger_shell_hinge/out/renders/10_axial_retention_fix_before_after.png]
minh hoa truoc/sau vai chan chong tuot truc

*Trái: trục CŨ — nửa lòng tay trượt thẳng ra ngoài (dịch 20mm, 0mm³ giao nhau, không có gì cản). Phải: trục MỚI — 2 vai chặn hình trụ (khối đen) chặn đường trượt, nửa lòng tay đâm xuyên vào vai chặn (dịch 4mm, ~9.9mm³ giao nhau) trước khi có thể đi xa hơn.*

**Đã kiểm tra lại toàn bộ sau khi sửa (không hồi quy):** `check_hinge_sweep.py` vẫn PASS (0.0246mm³ tối đa trong vùng mở thật, không đổi so với §5e — vai chặn nằm ẩn trong boss sẵn có nên không ảnh hưởng va chạm khi xoay), `check_connectivity.py` PASS (1 khối liền cho cả `.py`/`.scad`), `check_latch_engagement.py` PASS (không đổi so với §5c), `cross_check.py` PASS (`.py` và `.scad` khớp hình học, lệch thể tích <0.3%).

**Giới hạn tự khai (QUAN TRỌNG):** đây là bằng chứng HÌNH HỌC rằng cần đâm xuyên vật liệu mới trượt qua được vai chặn — **KHÔNG phải** bằng chứng về LỰC cần thiết để thực sự kéo tuột (độ bền kéo/cắt của PETG tại vùng vai chặn, độ đàn hồi khi lắp ráp lần đầu lên trục, dung sai in thật). Bán kính/chiều dài vai chặn (2.2mm / 2.0mm) là **lựa chọn thiết kế trên CAD**, chưa kiểm chứng bằng mẫu in thật hay thử lực kéo — vẫn cần in thử và thử kéo tay trước khi coi là "chắc chắn không rơi ra" trong thực tế. Lỗi này cũng là ví dụ cụ thể cho bài học ở §5e: **một bộ kiểm tra chỉ quét 1 loại chuyển động (góc xoay) sẽ bỏ sót lỗi ở loại chuyển động khác (trượt dọc trục)** — từ nay cả `check_hinge_sweep.py` (xoay) VÀ `check_axial_retention.py` (trượt dọc trục) đều chạy mỗi khi đổi tham số hình học liên quan đến bản lề.

**Đính chính 2026-10-08 (phát hiện khi làm QA bằng ảnh render + đo thể tích boolean chính xác, theo yêu cầu "dùng vision kiểm tra tới khi hết lỗi"):** câu mô tả ban đầu ở trên — vai chặn "ẩn gọn trong khối vật liệu có sẵn, không tạo gờ nhô mới ra ngoài vỏ" — **đã được đo lại và SAI**. Đo bằng phép `cut(top_shell CÓ vai chặn, top_shell KHÔNG có vai chặn)` cho ra **~24mm³ vật liệu MỚI**, nằm hoàn toàn ở `Z ∈ [-2.2, 0]` (nửa không gian của lòng tay), lý do: boss khớp ống của nửa mu tay chỉ là **nửa hình trụ** (`intersect` với nửa không gian `Z ≥ 0`, xem `add_hinge_knuckles()`), trong khi vai chặn là **hình trụ tròn đủ** (cả 2 nửa `Z`) — nên nửa `Z < 0` của mỗi vai chặn **lộ ra** thành 1 cục u nửa-hình-trụ nhỏ (bán kính 2.2mm, dài 2mm) ngay trong khe hở (`knuckle_gap`) giữa các khớp ống, phía lòng tay.

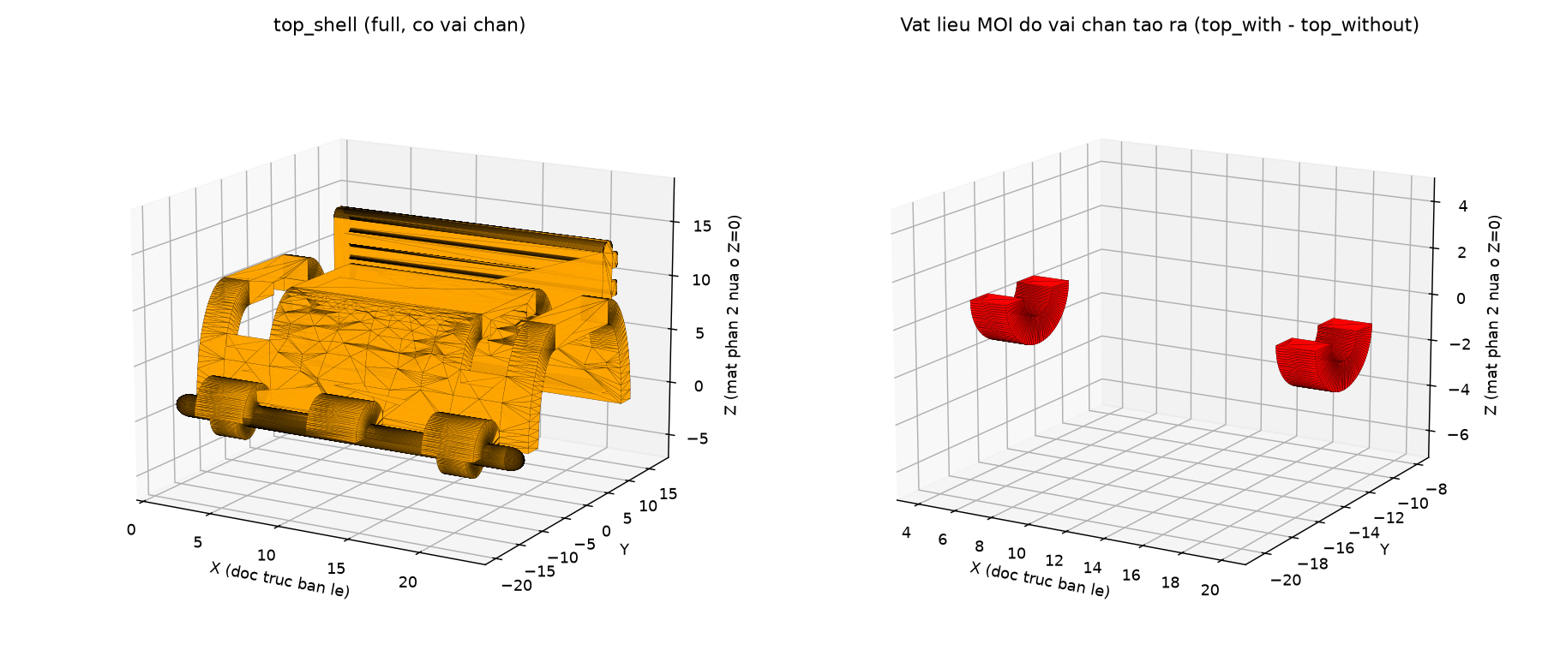
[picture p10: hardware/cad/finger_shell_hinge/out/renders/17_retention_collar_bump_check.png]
kiem tra cuc u vai chan bang vision + do the tich

*Trái: toàn bộ `top_shell` (có vai chặn). Phải: CHỈ phần vật liệu MỚI do vai chặn tạo ra (kết quả `cut`), tách riêng ra để thấy rõ 2 cục u nửa-hình-trụ — không phải lỗi dựng lưới, là vật liệu CSG thật.*

Đây **không phải lỗi hình học/va chạm** — đã xác nhận lại `check_hinge_sweep.py` vẫn PASS (0.0246mm³ tối đa, không đổi) sau khi biết điều này, và về mặt lý luận: cục u này **PHẢI tồn tại ở đúng nửa `Z<0`** thì vai chặn mới thực sự "chặn" được khớp ống nửa lòng tay (có lỗ nằm ở `Z<0`) — nếu giới hạn vai chặn về chỉ nửa `Z≥0` (để "ẩn" đúng nghĩa đen) thì sẽ **MẤT HOÀN TOÀN tác dụng chống tuột trục** đã chứng minh ở bảng trên. Cục u cũng **không vượt quá bán kính ngoài lớn nhất của vỏ** (2.2mm < `r_knuckle = 3.0mm`) nên không ảnh hưởng kích thước bao ngoài tổng thể hay các khe cài dây đai. Tóm lại: đây là một **đánh đổi thiết kế có chủ đích và cần thiết** (lộ nhẹ về thẩm mỹ trong khe hở, đổi lấy chức năng chống tuột trục hoạt động thật), **không phải** "ẩn hoàn toàn" như mô tả ban đầu — ghi chú trong code (`finger_shell_hinge.py` và `.scad`, định nghĩa `pin_retain_r`) đã được sửa lại cho khớp với số đo thật.

## 6a. Xoay hướng đặt lên bàn in để GIẢM SUPPORT tối đa (2026-10-08)

**Yêu cầu chủ dự án:** "xoay chỉnh sửa sao cho khi để lên slicer thì support tạo ra sẽ ít nhất đi".

Sandbox này **không có trình cắt lớp (slicer) thật** nào chạy được (không có PrusaSlicer/Cura CLI, không có mạng ra ngoài danh sách host cho phép) — nên không thể "mở file trong slicer rồi đếm số support" theo đúng nghĩa đen. Thay vào đó, đã viết `check_print_orientation.py` dùng đúng **tiêu chí hình học mà mọi slicer FDM dùng để quyết định sinh support**: một tam giác bề mặt cần support nếu nó **chúc xuống** và góc giữa pháp tuyến với phương ngang nhỏ hơn 45° (ngưỡng mặc định phổ biến của PrusaSlicer/Cura) — tính TRÊN CHÍNH lưới tam giác hoá thật của khối CAD (CadQuery `tessellate()`), không phải ước lượng bằng mắt.

**Cách làm:** quét **24 hướng đặt theo trục chính** (mọi cách "đặt phẳng 1 mặt xuống bàn rồi xoay quanh trục đứng" — đúng kiểu hay dùng khi tự xoay tay trong slicer), đo tổng diện tích overhang ở mỗi hướng, cho cả `top_shell_dorsal` và `bottom_shell_palmar`:

| Chi tiết | Hướng THIẾT KẾ GỐC (như xuất STL trước đây, không xoay) | Hướng TỐT NHẤT trong 24 hướng (đã chọn) |
|---|---|---|
| `top_shell_dorsal` | 522.2 mm² overhang (18.4% bề mặt) | **245.3 mm² (8.6% bề mặt)** — giảm 53% |
| `bottom_shell_palmar` | 249.1 mm² overhang (9.0% bề mặt) | **140.5 mm² (5.1% bề mặt)** — giảm 44% |

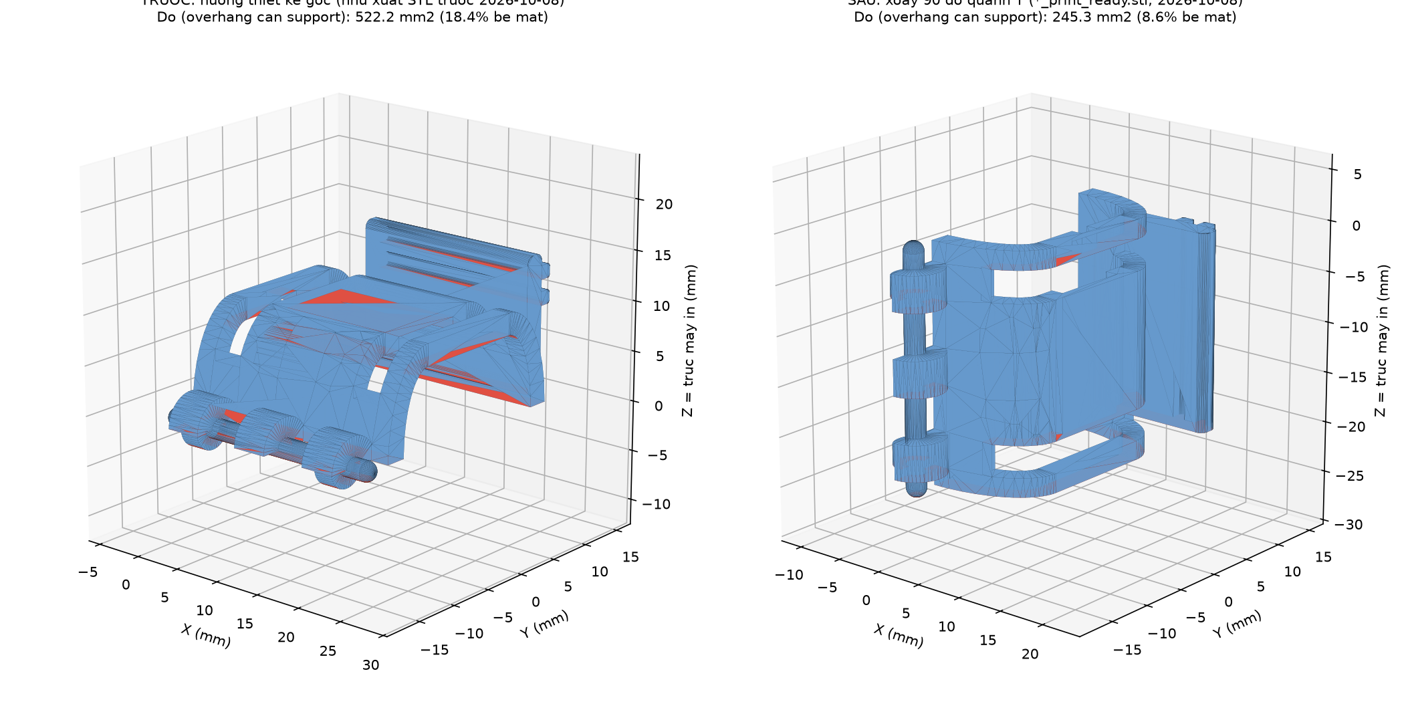
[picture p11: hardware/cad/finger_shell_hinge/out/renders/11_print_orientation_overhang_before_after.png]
so sanh overhang truoc/sau xoay huong in

*Tam giác màu ĐỎ = bề mặt cần support (chúc xuống >45° so với phương ngang). Trái: hướng thiết kế gốc. Phải: hướng đã xoay (90° quanh trục Y, trục bản lề thẳng đứng) — vùng đỏ giảm rõ rệt.*

**Hướng tốt nhất tìm được: xoay 90° quanh trục Y, đưa trục bản lề (trục X cục bộ) về THẲNG ĐỨNG, trùng trục Z máy in** — đây CHÍNH LÀ hướng đã được khuyến nghị bằng lời ở mục 6 bên dưới từ trước (để lỗ chốt in theo từng lớp tròn hoàn chỉnh) — nay được **xác nhận bằng số** là cũng tối ưu cho overhang, không phải 2 tiêu chí mâu thuẫn nhau. (Đã thử xoay thêm góc nghiêng nhỏ quanh 2 trục còn lại quanh hướng này — chỉ cải thiện thêm ~1 điểm % cho `top_shell_dorsal` và không đáng kể cho `bottom_shell_palmar`, trong khi đặt nghiêng làm mất mặt phẳng tựa bàn in ổn định — **không đáng đánh đổi**, giữ nguyên hướng xoay theo trục chính.)

**Đã triển khai — xuất sẵn file ĐÃ XOAY, không cần người dùng tự xoay tay trong slicer nữa:**
- `out/top_shell_dorsal_print_ready.stl` / `.step`
- `out/bottom_shell_palmar_print_ready.stl` / `.step`
- Bản `.scad` tương đương: `out/scad/top_shell_dorsal_print_ready.stl` / `out/scad/bottom_shell_palmar_print_ready.stl` (gọi qua `PART="top_print"`/`"bottom_print"`, module `top_shell_print_ready()`/`bottom_shell_print_ready()` — đã sửa dấu góc xoay từ `-90°` thành `+90°` cho khớp với hướng tối ưu tìm được, và thêm `translate()` nâng mảnh lên để đáy chạm đúng Z=0 mặt bàn in).
- Đã đối chiếu `cross_check.py`: 2 bản `.py`/`.scad` của cả 2 file print-ready khớp hình học (lệch thể tích 0.10%, bbox khớp) — không hồi quy.
- **Nạp các file `*_print_ready.stl` này thẳng vào slicer là đã đúng hướng khuyến nghị**, không cần dùng chức năng "đặt lại lên bàn in / lay flat" nữa (vẫn còn `top_shell_dorsal.stl`/`bottom_shell_palmar.stl` bản KHÔNG xoay để xem/chỉnh sửa CAD, không khuyến nghị in trực tiếp từ bản đó).

**Giới hạn tự khai (QUAN TRỌNG):** đây là **thước đo hình học thay thế (proxy)**, không phải chạy slicer thật — số mm² support THẬT sự mà PrusaSlicer/Cura sinh ra phụ thuộc thêm vào: cài đặt support cụ thể (góc ngưỡng, support kiểu "chỉ trên bàn in" hay "mọi nơi", mật độ, support tree/organic...), khả năng tự bắc cầu (bridging) của máy in/vật liệu với các khoảng hở nhỏ, và có thể khác đôi chút tuỳ bản slicer. 8.6%/5.1% diện tích còn lại (chủ yếu ở rìa khớp ống bản lề cantilever, tay đòn ngàm cài, mép hốc cảm biến) là **overhang nhỏ, cục bộ** — phần lớn nằm trong khả năng tự bắc cầu (bridge) của FDM thông thường mà không cần support thật sự, nhưng CHƯA kiểm chứng bằng slicer/máy in thật.

## 6. Hướng dẫn in 3D (khuyến nghị — chưa kiểm chứng bằng mẫu in thật)

- **Vật liệu:** PETG (đồng bộ với `docs/04` §6), ≥ 5 vòng tường, 100% hoặc ≥ 60% infill ở vùng ngàm/bản lề (chịu lực lặp lại).
- **Hướng in bản lề:** đặt sao cho **trục chốt (trục X của mảnh) thẳng đứng theo trục Z máy in** — lỗ chốt sẽ in theo từng lớp tròn hoàn chỉnh, không cần support, không bị méo do in ngang qua lỗ. **MỚI 2026-10-08 (xem §6a): dùng thẳng file `out/*_print_ready.stl` đã xoay sẵn đúng hướng này, không cần tự xoay tay trong slicer nữa.**
- **Hướng in ngàm/tay đòn:** tay đòn đàn hồi (`arm`) nên in với lớp vân (layer line) **vuông góc hướng uốn** để bền mỏi hơn — nghĩa là in đứng theo chiều dày `arm_t`, không in nằm phẳng.
- **Khớp ống xen kẽ (knuckle):** chừa khe in `knuckle_gap = 0.5 mm` đã tính sẵn trong tham số; nếu máy in dung sai lớn, tăng `knuckle_gap` lên 0.6–0.8 mm để tránh 2 mảnh dính nhau.
- **Chốt bản lề:** mặc định (`PIN_INTEGRATED = true`, xem mục 5b) trục đã **hàn liền vào `top_shell_dorsal.stl`** — in nửa mu tay là có sẵn trục, không cần in/lắp chốt riêng. File `hinge_pin.stl`/`.step` vẫn được xuất riêng chỉ để **tham khảo kích thước** (không cần in). Nếu đổi `PIN_INTEGRATED = false` để quay lại thiết kế chốt rời: nên dùng que nhựa/kim loại cứng có sẵn (que hàn nhựa, đinh ghim, hoặc đoạn dây đồng/thép Ø2 mm) thay vì in — in một que nhựa mảnh dài 20 mm bằng FDM dễ cong/gãy hơn là dùng vật liệu sẵn có (nhưng dễ thay thế hơn nếu gãy — xem đánh đổi ở mục 5b).
- **In "tại chỗ" (print-in-place) — MỚI 2026-10-07, xem §5e:** nạp thẳng **`out/assembly_open_print_in_place.stl`** (bản `.py`) hoặc **`out/scad/assembly_open.stl`** (bản `.scad`) vào slicer — file này chứa CẢ 2 nửa ở trạng thái MỞ, in 1 lần duy nhất, khớp ống nửa lòng tay bọc sẵn quanh trục với khe hở `pin_clearance = 0.3mm` (CHƯA hiệu chỉnh theo máy in thật — khuyến nghị in thử coupon nhỏ với vài mức khe hở trước). **KHÔNG dùng bản ở trạng thái đóng để in gộp** (ngàm cài sẽ bị dính liền, xem §5e). Tắt support trong vùng bản lề (slicer có thể đề xuất support vì thấy lỗ/khe hẹp — không cần, thiết kế đã tính để tự bắc cầu qua khe hở nhỏ).
- **Hốc cảm biến:** in xong cần làm phẳng nhẹ bề mặt hốc (giấy nhám mịn) trước khi dán sandwich Velostat + đồng, để tiếp xúc đều — đúng tinh thần `docs/04` §4.1 "điện trở tiếp xúc copper–Velostat... cần preload + kẹp cơ khí ổn định".

## 7. BOM cho 1 cụm (1 đốt ngón)

| # | Chi tiết | Nguồn |
|---|---|---|
| 1 | Nửa mu tay (A) — `top_shell_dorsal.stl` (đã bao gồm trục bản lề hàn liền, mặc định `PIN_INTEGRATED=true`) | In PETG |
| 1 | Nửa lòng tay (B) — `bottom_shell_palmar.stl` | In PETG |
| 0/1 | Chốt bản lề Ø~2 mm, dài ~22 mm | **Không cần** ở chế độ mặc định (trục đã hàn liền vào mảnh A); chỉ cần nếu đổi `PIN_INTEGRATED=false` — khi đó dùng que/dây cứng có sẵn (xem mục 5b/6), không bắt buộc in |
| 2 | Miếng sensing element Velostat + đồng tự dính | Theo `docs/04` §3/§6 (đã có trong BOM hệ thống) |
| 1–2 | Dây đai Velcro/thun phụ (qua `strap_slot`) | Tuỳ chọn, khóa an toàn lớp 2 |

Không cần bu-lông/đai ốc cho bản v1 (khác thiết kế bu-lông kẹp cũ ở `docs/04` §8) — đây chính là điểm đổi để bớt thao tác siết/nới quanh ngón tay.

## 8. Giới hạn tự khai — việc phải làm trước khi dùng thật

Theo đúng tinh thần `AGENTS.md` (không thăng cấp bằng chứng):

1. **Chưa in** — mọi nhận định "dễ đóng/mở, không đau, vừa khít" đều là **mục tiêu thiết kế**, chưa phải kết quả.
2. **Kích thước đốt ngón (`W_in`, `H_in`, `L`) là số giả định** — phải đo thước cặp trên người dùng thật (và nên làm 2–3 size như Oval-8 làm nhiều size).
3. **Preload mới có 2 nấc rời rạc (thô)** — chưa có vít vi chỉnh liên tục như bu-lông cũ; nếu GATE 0 (`research/protocols/08a`) cho thấy cần cửa sổ preload hẹp hơn 2 nấc có thể phân biệt, bản v2 cần thêm vít vi chỉnh (M2) tại khối ngàm.
4. **Chưa đo lực/độ bền mỏi của ngàm và bản lề** — số lần đóng/mở trước khi răng ngàm hoặc khớp ống mòn/gãy là chưa biết, phải đo (khuyến nghị ≥ 50 chu kỳ đóng/mở trên bench trước khi dùng cho GATE A/B).
5. **Chưa kiểm tra hốc cảm biến có giữ sandwich Velostat phẳng, đều áp suất khi đóng ngàm hay không** — cần kiểm bằng giấy cảm áp (pressure-sensitive film) hoặc quan sát trực tiếp trước khi tin số đo từ sensing element.
6. **Fit-to-skin / áp lực điểm (pressure point)** chưa đánh giá — bắt buộc kiểm tra không hằn da sau 15 phút đeo liên tục (tiêu chí đã có sẵn ở `docs/04` §6) trước khi coi là đạt.
7. Đây **không phải** thiết bị tập luyện/hỗ trợ lực — chỉ là khung cơ khí giữ cảm biến, đúng khung an toàn đã khóa ở `AGENTS.md` §4.

**Thứ tự việc làm tiếp theo (đề xuất, chờ owner duyệt `DEC-HW-006`):**
`đo thước cặp → cập nhật tham số → in 1 cặp thử → kiểm lắp/tháo định tính (có đau không, mất bao lâu) → đo lực đóng ngàm bằng lực kế cầm tay → (nếu đạt) dán sensing element → đưa vào `research/protocols/08a` GATE 0`.

## 9. Cấu trúc file

```
hardware/cad/finger_shell_hinge/
├── README.md                 ← file này
├── finger_shell_hinge.py     ← script CadQuery tham số — ĐÃ CHẠY THẬT trong sandbox, nguồn CAD chuẩn
├── finger_shell_hinge.scad   ← mã OpenSCAD tương đương — mở trực tiếp bằng OpenSCAD trên máy bạn
│                                (viết tay theo đúng công thức của bản .py; ĐÃ chạy qua chính OpenSCAD
│                                 2025.01.19 thật trong sandbox này qua openscad-wasm-prebuilt, và đối
│                                 chiếu khớp hình học với bản .py — xem mục 5, cross_check.py)
├── render_preview.py         ← dựng ảnh PNG xem nhanh từ STL CadQuery (matplotlib, không cần GPU)
├── render_scad_wasm.mjs      ← chạy chính engine OpenSCAD (qua Node.js) để render .scad ra STL, kiểm chứng
├── cross_check.py            ← so thể tích + bounding-box giữa out/*.stl (CadQuery) và out/scad/*.stl (OpenSCAD)
├── check_connectivity.py     ← kiểm tra mỗi chi tiết là 1 khối LIỀN (không tách mảnh rời) — xem §5a
├── check_latch_engagement.py ← kiểm tra móc/răng ngàm cài có THỰC SỰ giao nhau hình học — xem §5c
├── check_hinge_sweep.py      ← [MỚI 2026-10-07] quét va chạm 2 nửa vỏ qua TOÀN BỘ dải góc mở — xem §5e
├── check_axial_retention.py  ← [MỚI 2026-10-08] quét chuyển vị dọc trục, kiểm tra chống tuột — xem §5f
├── check_print_orientation.py ← [MỚI 2026-10-08] quét 24 hướng đặt bàn in, đo overhang — xem §6a
├── check_retention_collar_exposure.py ← [MỚI 2026-10-08] QA bằng vision + đo thể tích: xác nhận "cục u" lộ ra do vai chặn nằm trong giới hạn an toàn — xem §5f (mục "Đính chính 2026-10-08")
├── render_retention_collar_check.py ← [MỚI 2026-10-08] xuất ảnh minh hoạ cho check_retention_collar_exposure.py (out/renders/17_...)
├── package.json / package-lock.json  ← khai báo gói npm openscad-wasm-prebuilt dùng cho render_scad_wasm.mjs
└── out/
    ├── top_shell_dorsal.step / .stl       ← nửa mu tay (mang khối ngàm + 3 khớp bản lề), hướng CAD gốc (để chỉnh sửa, KHÔNG khuyến nghị in trực tiếp)
    ├── bottom_shell_palmar.step / .stl    ← nửa lòng tay (mang tay đòn ngàm + 2 khớp bản lề), hướng CAD gốc
    ├── top_shell_dorsal_print_ready.step / .stl     ← [MỚI 2026-10-08] ĐÃ XOAY sẵn hướng overhang tối thiểu — xem §6a, dùng file này để in
    ├── bottom_shell_palmar_print_ready.step / .stl  ← [MỚI 2026-10-08] tương tự, nửa lòng tay
    ├── hinge_pin.step / .stl              ← chốt bản lề (tham khảo kích thước, xem mục 6)
    ├── assembly_closed.step / assembly_open.step   ← lắp ráp 2 trạng thái (có màu, mở bằng FreeCAD/Fusion/...)
    ├── assembly_closed__{top,bottom}.stl / assembly_open__{top,bottom}.stl  ← mesh từng trạng thái (chỉ để XEM)
    ├── assembly_open_print_in_place.stl   ← [MỚI 2026-10-07] file IN THẬT gộp 2 nửa (trạng thái MỞ) — xem §5e
    ├── renders/                           ← ảnh PNG xem nhanh từ bản CadQuery (dùng trong README này)
    └── scad/                              ← STL xuất từ chính OpenSCAD (render_scad_wasm.mjs) — dùng để đối chiếu
                                              (scad/assembly_open.stl cũng dùng được để in-tại-chỗ, xem §5e;
                                               scad/*_print_ready.stl đối chiếu với bản .py, xem §6a)
```

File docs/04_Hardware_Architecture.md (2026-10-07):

# 04 — Kiến trúc phần cứng

> **Ngày:** 2026-09-13 · **Quyết định liên quan:** DEC-HW-003 (ESP32-S3 thay Mega 2560), DEC-HW-004 (bố trí kênh).
> **Trạng thái:** **thiết kế trên giấy**. Mọi con số về nhiễu/độ phân giải/tốc độ khung dưới đây là **ngân sách dự kiến (design budget)**, phải **đo lại trên bench** trước khi đưa vào báo cáo.
> **Không** được trích các số trong tài liệu này như kết quả thực nghiệm.

---

## 1. Sơ đồ tổng thể

```
        ┌──────────── Mảng sensing element (12–24 kênh) ────────────┐
        │  Velostat + copper tape, dán trên vách khung in 3D        │
        └───────────────────────────┬───────────────────────────────┘
                                    │ tín hiệu tương tự
                        ┌───────────▼───────────┐
                        │  CD74HC4067 (16:1)     │  ×1 (cấu hình 12 kênh)
                        │  chọn kênh bằng 4 GPIO │  ×2 (cấu hình 24 kênh,
                        └───────────┬───────────┘   chọn chip bằng chân EN)
                                    │ 1 đường analog
                        ┌───────────▼───────────────────────────┐
                        │  ESP32-S3                             │
                        │  · ADC1 12-bit + lấy trung bình N mẫu │
                        │  · quét kênh → frame + CRC            │
                        │  · BLE 5 (không dây) / UART (bench)   │
                        └───────────┬───────────────────────────┘
                                    │
                        ┌───────────▼───────────────────────────┐
                        │  Orange Pi 5 Pro (RK3588)             │
                        │  · bù ảnh hưởng drift                 │
                        │  · trích đặc trưng → vector lực       │
                        │  · suy luận hướng khớp → bàn tay 3D   │
                        │  · mô hình INT8 (RKNN) trên NPU       │
                        └───────────┬───────────────────────────┘
                                    │
                        Dashboard theo tuần (KTV/bác sĩ)
```

---

## 2. Vì sao ESP32-S3 thay Arduino Mega 2560 (DEC-HW-003)

| Tiêu chí | Arduino Mega 2560 | **ESP32-S3** | Kết luận |
|---|---|---|---|
| ADC | 10-bit, 16 kênh | 12-bit danh định (ADC1), 2 khối SAR | ESP32-S3 |
| Tốc độ | 16 MHz, 8-bit AVR | 240 MHz, dual-core, có gia tốc vector cho NN | ESP32-S3 |
| Truyền dữ liệu | UART/USB có dây | BLE 5 + Wi-Fi + USB-OTG | ESP32-S3 (bắt buộc cho thiết bị đeo tại nhà) |
| Mức logic | 5 V → **cần level shifter** sang Orange Pi 3.3 V | **3.3 V** → khớp trực tiếp | ESP32-S3 (bớt một rủi ro điện) |
| Kích thước/tiêu thụ | To, tốn điện | Nhỏ, có chế độ ngủ | ESP32-S3 |
| Số chân analog | 16 chân ADC rời | **ít chân ADC** (ADC1 dùng được ~7–8 chân trên nhiều board) → **cần MUX** | Hoà, nhưng MUX là bắt buộc |

**Đánh đổi phải ghi nhận trung thực:** ADC của ESP32-S3 **không tuyến tính hoàn hảo** và nhạy với cấu hình (suy giảm khi bật Wi-Fi). Vì vậy:
- chỉ dùng **ADC1**; nếu cần truyền không dây thì ưu tiên **BLE**, tránh Wi-Fi trong lúc đo;
- phải **hiệu chuẩn ADC** (đường cong hiệu chỉnh theo điện áp chuẩn) trước khi dùng;
- phải ghi lại nhiệt độ/điện áp nguồn trong log để truy vết.

---

## 3. Bố trí kênh

### 3.1 Cấu hình 1 — Tối thiểu khả thi (12 kênh, 1 MUX) — *dùng cho bring-up và GATE 0/A*

| Kênh | Vị trí | Vách đo | Ghi chú |
|---|---|---|---|
| CH0 | Ngón trỏ – MCP | phía lòng bàn tay (flexor side) | |
| CH1 | Ngón trỏ – PIP | phía lòng bàn tay | |
| CH2 | Ngón giữa – MCP | phía lòng bàn tay | |
| CH3 | Ngón giữa – PIP | phía lòng bàn tay | |
| CH4 | Ngón áp út – MCP | phía lòng bàn tay | |
| CH5 | Ngón áp út – PIP | phía lòng bàn tay | |
| CH6 | Ngón út – MCP | phía lòng bàn tay | |
| CH7 | Ngón út – PIP | phía lòng bàn tay | |
| CH8 | Ngón cái – MCP | vách đối diện (opposition) | |
| CH9 | Ngón cái – IP | vách đối diện | |
| CH10 | Lòng bàn tay (khối thenar) | pháp tuyến | lực cầm nắm |
| CH11 | **Ô tham chiếu** | trên nẹp cổ tay, không chịu tải người dùng | đo trôi hệ thống |

**Hạn chế của cấu hình 1 (phải nói thẳng):** mỗi khớp chỉ có **một vách** ⇒ chỉ biết *độ lớn*, chưa phân biệt được **dấu** gập/duỗi một cách chắc chắn. Dấu được suy ra từ **so sánh với đường nền (baseline) động**, kém tin cậy hơn đo vi sai.

### 3.2 Cấu hình 2 — Đầy đủ, đo vi sai (24 kênh, 2 MUX) — *dùng cho GATE A/B/C*

Mỗi khớp có **cặp sensing element đối xứng** trên hai vách đối diện:

| Nhóm | Số khớp | Số kênh |
|---|---|---|
| 4 ngón dài × 2 khớp (MCP, PIP) × 2 vách | 8 | 16 |
| Ngón cái × 2 khớp (MCP, IP) × 2 vách | 2 | 4 |
| Lòng bàn tay × 2 vùng | — | 2 |
| Ô tham chiếu | — | 2 (đặt cạnh nhau, kiểm tra chéo) |
| **Tổng** | | **24** |

Với 24 kênh dùng **2 × CD74HC4067**: cả hai MUX đưa tín hiệu về **cùng một chân ADC1**, chọn bằng chân **EN** (chỉ một chip hoạt động tại mỗi thời điểm) → tránh phải dùng ADC2 (ADC2 dùng chung tài nguyên với Wi-Fi).

> **Nguyên tắc thiết kế cơ khí đi kèm:** mỗi sensing element phải được **kéo trước (preload)** một lực nhỏ, xác định, để tín hiệu có cả nhánh dương và nhánh âm quanh điểm làm việc. Không preload thì không đo được chiều.

---

## 4. Ngân sách độ phân giải

### 4.1 Chuỗi tín hiệu
```
Velostat (R_sensor thay đổi theo lực)
   → cầu phân áp với R_f
   → CD74HC4067 (R_on ~ 50–70 Ω ở 5 V, thấp hơn nhiều so với R_sensor)
   → ADC1 của ESP32-S3
```

**Chọn R_f:** độ nhạy `dV/dR` cực đại khi `R_f ≈ R_sensor`. Vì R_sensor của sensing element tự chế **chưa được đo** 🔵, quy trình bắt buộc là:
1. Đo R_sensor ở các mức tải khác nhau (bench, có load cell tham chiếu).
2. Chọn R_f nằm giữa dải làm việc (dự kiến hàng chục kΩ — 🔵 phải đo).
3. Ghi lại đường cong `ADC ↔ lực` cho từng sensing element (không dùng chung một đường cong cho mọi kênh).

### 4.2 Ngân sách nhiễu (dự kiến — phải đo lại)

| Nguồn | Ảnh hưởng dự kiến | Cách xử lý |
|---|---|---|
| Lượng tử hóa ADC 12-bit | ~1 LSB ≈ 0,8 mV trên dải 3,3 V | — |
| Nhiễu ADC ESP32-S3 (ENOB thực ~9–10 bit) | vài LSB | Lấy trung bình N mẫu |
| Nhiễu nguồn/đường dẫn | phụ thuộc layout | Tụ lọc, dây ngắn, mass chung chắc chắn |
| Điện trở tiếp xúc copper–Velostat | có thể lớn, thay đổi theo tải | Preload + kẹp cơ khí ổn định |

**Lấy trung bình:** nhiễu ngẫu nhiên giảm theo `√N`.
- N = 16 → giảm ~4 lần (~2 bit hiệu dụng) → **~11 bit hiệu dụng**.
- N = 64 → giảm ~8 lần (~3 bit) → đổi lại tốc độ khung giảm.

> Đây là **ước lượng lý thuyết**. Giá trị thật của ENOB **phải đo bằng log** (đo với đầu vào cố định rồi tính độ lệch chuẩn).

---

## 5. Ngân sách tốc độ khung

Giả định mỗi kênh cần **thời gian ổn định (settling) + lấy mẫu**: `t_ch ≈ 100–300 µs` khi đã lấy trung bình nhiều mẫu (🔵 đo lại thực tế).

| Cấu hình | Số kênh | t_ch | Thời gian 1 vòng quét | Tốc độ khung (không nghỉ) |
|---|---|---|---|---|
| 12 kênh | 12 | 200 µs | 2,4 ms | **~415 Hz** |
| 24 kênh | 24 | 200 µs | 4,8 ms | **~208 Hz** |
| 24 kênh | 24 | 300 µs | 7,2 ms | **~139 Hz** |

**Nhu cầu thực tế:** động tác phục hồi chức năng có tần số thấp (khoảng **0,5–2 Hz**). Theo nguyên lý lấy mẫu, tốc độ khung **≥ 20–50 Hz** đã đủ để bắt dạng sóng lực mà không mất thông tin quan trọng. Vì vậy:
- **Mục tiêu thiết kế: 45–100 Hz** (rộng rãi so với yêu cầu), dành phần dư cho lấy trung bình và truyền BLE.
- Có thể **giảm tốc độ khung để tăng độ phân giải** nếu GATE 0 cho thấy nhiễu là yếu tố giới hạn.
- Phải ghi rõ trong log: số mẫu trung bình N, tốc độ khung thực đo, và độ trễ end-to-end.

---

## 6. Đóng gói khung găng

| Thành phần | Vật liệu / cách làm | Rủi ro |
|---|---|---|
| Khung cứng định vị lóng ngón | In 3D (PLA/PETG); khe hở điều chỉnh được | Cứng quá → cấn, không thoải mái; lỏng quá → mất tín hiệu |
| Lớp đệm tiếp xúc | TPU mềm / xốp mỏng | Ảnh hưởng preload |
| Dây dẫn | Dây mảnh dọc mu bàn tay, gom về hộp mạch ở cổ tay | Đứt dây khi gập nhiều lần |
| Hộp mạch | In 3D, gắn ở ngoài cổ tay | Khối lượng/kích thước ảnh hưởng tính khả dụng |
| Chống trượt | Dây đai Velcro quanh cổ tay + đai từng ngón | Xoay/trượt làm sai vị trí kênh |

**Tiêu chí công thái học tối thiểu cần đạt (phải đo, không được nói suông):**
thời gian mang/tháo (don–doff) ở mức người nhà làm được trong ~1 phút; khối lượng tổng; không gây đau khi đeo 15 phút; không cấn khi gập tối đa.

> **2026-10-07 — ĐỀ XUẤT đổi cơ chế "khung cứng định vị lóng ngón" ở dòng đầu bảng trên** (chưa chốt, xem `DEC-HW-006`/`CLM-HW-004`):
> thay vì ống gần-kín + bu-lông kẹp vi chỉnh (phải luồn/ép ngón tay liệt/co cứng qua vòng kín, rồi siết bu-lông quanh ngón), dùng khung **vỏ-sò 2 mảnh nối bằng bản lề trục in 3D ở 1 cạnh + ngàm cài nhanh ở cạnh kia** — đặt ngón vào nửa đang mở, gập nửa kia xuống, cài ngàm, không cần xỏ/siết quanh ngón. CAD tham số (CadQuery, xuất STEP/STL) + phân tích tham khảo thị trường + việc-phải-làm trước khi dùng thật: [`hardware/cad/finger_shell_hinge/README.md`](../hardware/cad/finger_shell_hinge/README.md). **Chưa in, chưa đo lực/preload, chưa thay thế bu-lông kẹp trong BOM §8** cho tới khi owner duyệt + có số đo bench.

---

## 7. Việc phải làm trước khi viết bất kỳ kết luận nào

1. ☐ Chốt cấu hình 1 hay 2 (hoặc lộ trình 1 → 2) — và chốt `DEC-SCOPE-005` (3 ngón như bản nộp hay giữ lộ trình 5 ngón).
2. ☐ Đo `R_sensor` theo tải cho ≥ 5 mẫu sensing element tự chế.
3. ☐ Đo ENOB thực của chuỗi ADC + MUX.
4. ☐ Đo tốc độ khung và độ trễ end-to-end thực tế.
5. ☐ Ghi toàn bộ vào `research/bench/` và `research/evidence/SOURCE_LEDGER.csv` (loại `raw_measurement`).
6. ☐ Sau đó mới chạy `research/protocols/06_glove_hand_GATE_experiment.md`.

---

## 8. Cấu hình ĐÃ NỘP (`docs/DE_CUONG.pdf` §8–§9, 2026-09-26) — chờ `DEC-HW-005`

> Các §1–§7 ở trên là **ngân sách thiết kế trên giấy** (ESP32-S3 ADC 12-bit, `V_EX = 3,1 V`, 6 IMU, lộ trình 5 ngón).
> Bản nộp dùng chuỗi khác. **Không xóa §1–§7** (lịch sử thiết kế); khi `DEC-HW-005` được chốt thì §8 này thành cấu hình hiện hành
> và `protocols/08` §3 + `docs/02` §5.5 phải tính lại theo LSB mới. Chi tiết: `CLM-HW-003`, sync review §2-F6.

```
[Tầng 1 — tay]  12 sensing element Velostat (khung ốp ngón PETG in 3D, điện cực đồng 0,05 mm,
                bu-lông kẹp vi chỉnh preload F_p) + 1 ô tham chiếu không tải
                + 1 IMU 6-DOF LSM6DS3 ở mu tay (bù góc nghiêng trọng trường)
[Tầng 2 — cổ tay] 2× CD74HC4067 (chuyển mạch 1 kHz) → MCP6001 đệm
                → cầu vi sai ΔV = V(lòng) − V(mu), R_ref = 10 kΩ (0,1 %, 25 ppm/°C)
                → INA333 G = 10 (CMRR ≥ 100 dB) → ADS1115 16-bit (±2,048 V, 62,5 µV/LSB, 860 SPS)
                → ESP32-S3 (lọc IIR bậc 2 fc = 10 Hz, Notch 50 Hz, BLE 5.0)
                → nguồn LiPo 3,7 V qua TP4056 + LDO HT7333 (cách ly lưới điện)
                + SHT30 bù trôi nhiệt–ẩm
[Tầng 3 — biên] Orange Pi 5 Pro (RK3588, NPU 6 TOPS): suy luận INT8 < 15 ms,
                tính EI/GAP/RAL + dashboard
```

**Bảng delta so với ngân sách §1–§5:**

| Hạng mục | Ngân sách cũ (§1–§5) | Bản nộp (§8–§9 PDF) |
|---|---|---|
| ADC | ESP32-S3 ADC1 12-bit (~1,51 mV/LSB danh định) | **ADS1115 16-bit rời** (62,5 µV/LSB, dải ±2,048 V) |
| Khuếch đại | không có (cầu phân áp thụ động, `R_f ≈ R_sensor`) | **INA333 G = 10**, `R_ref = 10 kΩ` 0,1 % |
| Đệm / bù môi trường | chưa có | MCP6001 + **SHT30** |
| IMU | 6 IMU (góc AROM/PROM + tốc độ kéo) | **1 IMU LSM6DS3** (bù nghiêng) — ⚠️ nguồn đo góc cho GAP còn mở (**I7**) |
| Lấy mẫu | mục tiêu 45–100 Hz, sàn 20 Hz | ⚠️ PDF ghi **cả 50 Hz** (§8.1/§9.1) **và 20 Hz** (M5/C1.10) — **I1** |
| Lọc số | chưa định | IIR bậc 2 fc = 10 Hz + Notch 50 Hz |
| Ngón | lộ trình 5 ngón (cấu hình 1/2) | **3 ngón** (cái/trỏ/giữa) — `DEC-SCOPE-005` |
| Kênh vi sai | 24 kênh vi sai (cấu hình 2) | "**12 kênh vi sai**" trên 6 khớp — ⚠️ chưa rõ 12 cặp hay 12 phần tử (**I6**) |
| Nguồn | chưa định | LiPo 3,7 V + TP4056 + HT7333 |

**Quy tắc vận hành đi kèm (PDF §9.3/§11.2):** auto-zero 3 s duỗi nghỉ đầu phiên (`V_offset` trừ trực tiếp);
cảnh báo kiểm tra cơ khí khi trôi tĩnh vượt **±5 %** dải đo so với ô tham chiếu; vòng lặp 1 (`V_base` → chỉnh găng),
vòng lặp 2 (phương sai → nhãn **"Nghi vấn"** + loại khỏi xu hướng + đo lại).

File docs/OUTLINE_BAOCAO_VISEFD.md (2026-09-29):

# OUTLINE BÁO CÁO TOÀN VĂN — ViSEF

## Đề tài: Nghiên cứu và phát triển găng tay thông minh hỗ trợ đánh giá và theo dõi chức năng vận động bàn tay trong phục hồi chức năng sau đột quỵ

> **Học sinh:** Văn Ngọc Nhật Anh (11A2) + Nguyễn Duy Quân (12A1) — THPT Quảng Trị · GVHD: Lê Công Long
> **Phiên bản:** v3.0 — 2026-09-29 (đồng bộ cấu hình đã nộp ADS1115+INA333; áp dụng checklist M-01..M-27; chốt đồ nghề + trần E2E; AI chuyển thành thực nghiệm đối chứng; bỏ mục tiêu 3D/clinical)
> **"Viên đạn":** Theo dõi định lượng chức năng bàn tay tại nhà, liên tục giữa các lần tái khám lâm sàng.
> **Lưu ý:** Mọi ô `[X]` chỉ được điền **sau** khi đo. Không bịa số. Xem `AGENTS.md`. Mọi claim vượt dữ liệu bị cấm — xem B.9.

---

## A. VẤN ĐỀ NGHIÊN CỨU

### 1. Lý do chọn đề tài

*(Bản văn ở `docs/bao_cao/A1_ly_do_chon_de_tai.md` — đã sửa cite theo M-22/M-23/M-24.)*

Cấu trúc đoạn:
- Gánh nặng đột quỵ + di chứng liệt/yếu tay; vì sao đây là vấn đề con người, không phải vấn đề kỹ thuật. Số "1,5 triệu di chứng" ghi rõ là **ước tính của nhóm từ [1]**, không phải số in trong [1] (M-22).
- Phục hồi bàn tay = luyện tập tại nhà; kỹ thuật viên chỉ gặp bệnh nhân mỗi 1–3 tháng → quãng giữa là **"hộp đen"**.
- Công cụ hiện tại (FMA, ARAT, Box and Block, lực kế Jamar, E-Link) là **ảnh chụp tại thời điểm đo**, chi phí cao, chủ yếu ở cơ sở y tế. Tự ghi chép thủ công sai số lớn (Manumeter 2022).
- Xác nhận độc lập: hội đồng chuyên gia quốc tế 2024 (DOI 10.1109/OJEMB.2024.3523442) + nghiên cứu OTHER 2026 🔵 verify + **tham khảo ẩn danh** KTV VLTL-PHCN (DEC-ROLE-001: không tên, không năm kinh nghiệm, không quan hệ).
- Câu chốt tên đề tài + một câu mô tả giải pháp (vi sai hai vách + EI/GAP/RAL + trạm biên).

### 2. Mục tiêu nghiên cứu

*(Bản chốt ở `docs/bao_cao/A2_muc_tieu.md`)*
- Chế tạo găng 3 ngón (cái/trỏ/giữa): 12 phần tử Velostat trên khung vách cứng tiền tải + 1 ô chuẩn + 1 IMU mu tay.
- Xây dựng chuỗi đo vi sai hai vách (lòng–mu) + auto-zero + **định lượng phần dư** (không nói "triệt tiêu hoàn toàn").
- Trích xuất bộ ba chỉ số EI/GAP/RAL kèm nhãn độ tin cậy (công thức EI viết tường minh trước khi thu dữ liệu — M-25).
- Xây dựng trạm biên: thu log → kiểm soát chất lượng → dashboard + timeline sự kiện → báo cáo tuần cho KTV từ xa.
- Kiểm định toàn bộ trên giàn + phantom theo ngưỡng đăng ký trước (M1–M6 + C1.1–C1.10) + 1 thực nghiệm đối chứng luật-thường-vs-ML.

### 3. Tiêu chí của dự án

*(Bản chốt ở `docs/bao_cao/A3_tieu_chi.md`; số đo điền sau khi có log)*

| Mã | Chỉ tiêu | Ngưỡng (đăng ký trước) |
|---|---|---|
| M1/C1.2 | SNR tại ΔF = 1 N (≥10/12 kênh) | ≥ 18 dB |
| M2/C1.3 | γ, R² (dải 0,5–10 N) | γ ≥ 0,25; R² ≥ 0,90 |
| M3/C1.4/C1.5 | CV nội phiên / liên ngày | ≤ 5% / ≤ 8% |
| M4/C1.8 | Trôi/tín hiệu sau 10 ngày (+ auto-zero) | ≤ 2,0 |
| M5/C1.10 | fs toàn 12 kênh / trễ hệ thống | ≥ 20 Hz (danh định — M-02) / ≤ 500 ms |
| M6 | Phát hiện đeo sai (cửa sổ V_base, N = 20–30) | tỷ lệ phát hiện ≥ 80% |
| C1.1 | Sàn nhiễu / 5.000 mẫu tĩnh | Vpp ≤ 5 mV |
| C1.6/C1.7 | Hysteresis / creep (60 s @ 5 N) | h ≤ 18% / ≤ 8% |
| C1.9 | Đồng đều giữa các kênh | ≤ ±40% (+ bảng chuẩn hóa) |

### 4. Đối tượng và phạm vi nghiên cứu

*(Bản chốt ở `docs/bao_cao/A4_doi_tuong_pham_vi.md`)*
- **Kỹ thuật (đã nộp):** 12 phần tử + ô chuẩn + 1 IMU; cầu vi sai → INA333 → 2×CD74HC4067 → MCP6001 → ADS1115 → ESP32-S3 → BLE → Orange Pi 5 Pro (trạm dùng chung của trường).
- **Y sinh:** di chứng yếu/liệt tay sau đột quỵ — nghiên cứu nền; giai đoạn này chỉ bench/phantom.
- **Người đeo (M-26, TODO):** ghi rõ ai đeo (kể cả thành viên nhóm), khi nào, biện pháp an toàn (pin, cách ly, không lực tác động lên người).
- **Giới hạn:** không chẩn đoán; không can thiệp/vận động hộ trên người (AAN chỉ trên phantom); không thay thế đánh giá lâm sàng; không claim lâm sàng.

### 5. Địa điểm nghiên cứu và thực nghiệm

*(Bản chốt ở `docs/bao_cao/A5_dia_diem.md`)*
- Phòng thực hành vật lý, phòng sáng tạo trường THPT Quảng Trị, và tại nhà (09/2026–02/2027).
- Tham khảo thực tiễn: **01 KTV VLTL-PHCN (ẩn danh)** phản biện giao thức đo trên giấy — bằng chứng **nhu cầu**, không phải bằng chứng **kết quả**.

### 6. Phương pháp nghiên cứu

*(Bản chốt ở `docs/bao_cao/A6_phuong_phap.md`)*
- **Tổng quan tài liệu:** prior art găng cảm biến; công cụ đánh giá tay; đặc tính Velostat; hệ thống theo dõi tại nhà.
- **Tham khảo ý kiến:** KTV VLTL-PHCN (phiếu + ghi chép, ẩn danh) + chuyên gia độc lập.
- **Thực nghiệm bench:** chuẩn lực tĩnh = **quả cân đã cân (F = m·g)**; DMM chính FNIRSI 2C23T (spec datasheet) + scope/gen của máy + load cell 5 kg (sau khi có HX711); C1.1 đo bằng ADS1115 tự log + scope chứng kiến.
- **Thống kê (đăng ký trước):** CV, R², h, creep, tỷ số trôi, recall/precision (M6, E1–E4). Không hạ chuẩn sau khi thấy số.

---

## B. GIẢI PHÁP VÀ THIẾT KẾ

### 1. Tổng quan đề tài

**Sơ đồ pipeline (chốt theo cấu hình đã nộp + M-04/M-16/M-17):**

```
Bàn tay (3 ngón: cái/trỏ/giữa) · 2 khớp/ngón × 2 vách = 12 phần tử + 1 ô chuẩn
      ↓ [kênh = phần tử đơn; mỗi khớp = 1 cặp vi sai d = S_lòng − S_mu]
Cầu chia áp (R_ref = 10 kΩ 0,1%) → INA333 (G = [X] sau M-01) → 2×CD74HC4067
      ↓ [Vex = [X] TODO M-17]
MCP6001 → ADS1115 (16-bit, LSB 62,5 µV) → ESP32-S3 (lọc, auto-zero, BLE 20 Hz)
      ↓
Orange Pi 5 Pro — TRẠM ĐO (trường đã có):
  ├─ Thu log + database phiên đo
  ├─ Kiểm soát chất lượng 2 vòng lặp (V_base + phương sai phiên)
  ├─ Trích xuất EI/GAP/RAL + nhãn tin cậy
  ├─ Dashboard + timeline sự kiện + báo cáo tuần (PDF)
  ├─ Camera đối chứng góc (P1) + thực nghiệm E1–E4 rules-vs-ML (P1)
  └─ Không suy luận gập/duỗi bằng ML (dấu vi sai đã làm việc đó — M-08)
      ↓ [file báo cáo chuyển tay — không claim cloud]
KTV xem từ xa → duyệt cờ đỏ → quyết định chuyên môn (AI sàng lọc, người quyết định)
```

**Nguyên lý cơ khí (điểm kỹ thuật trung tâm):**
ngón tì vào vách khung → nén phần tử trên vách đó → cặp vi sai lòng–mu cho dấu hướng (d > 0 gập, d < 0 duỗi) + biên độ lực; IMU mu tay bù nghiêng + chuẩn hóa vận tốc góc. Drift đồng pha **giảm** ở tầng vi sai + auto-zero, **phần dư định lượng** qua C1.8.

### 2. Bất cập của các giải pháp hiện tại và giải pháp đề tài

| Giải pháp hiện tại | Bất cập | Giải pháp của đề tài |
|---|---|---|
| Lực kế Jamar | Chỉ đo tổng lực bóp, một thời điểm, cần người đo | Theo dõi tại nhà, nhiều ngón, theo thời gian |
| Hệ thống E-Link | Chi phí cao, chỉ ở cơ sở y tế | Linh kiện rẻ, dùng được tại nhà |
| Găng tay IMU/flex thương mại | Đắt theo số trục, trôi, cồng kềnh | Vách khung + vật liệu piezoresistive, mã hóa cả hướng và lực |
| Găng tay phục hồi chức năng chủ động (robot găng) | Gây phụ thuộc máy, rủi ro an toàn, cần người có chuyên môn | **Không can thiệp vào vận động** — chỉ đánh giá/theo dõi |
| Đeo cảm biến ở cổ tay | Không ghi được chuyển động ngón; không phân biệt vận động có mục đích | Đo tại từng khớp ngón |
| Phần mềm mô phỏng (RehabReach và tương tự) | Mô phỏng, thiếu vi cử động và không tương tác thực | Đo trực tiếp; 🔵 cần xác minh thông tin RehabReach trước khi đưa vào báo cáo |

> **Khoảng trống thật:** chưa có hệ thống nào **vừa rẻ, vừa tại nhà, vừa tạo ra dữ liệu định lượng chức năng bàn tay theo tuần**, dùng được bởi người không chuyên môn và theo dõi được bởi kỹ thuật viên từ xa — **và tự biết khi nào dữ liệu của mình không còn đáng tin**.

### 3. Thiết kế phần cứng

*(Chi tiết đầy đủ: `docs/04_Hardware_Architecture.md` §8)*

| STT | Linh kiện | SL | Chức năng | Trạng thái |
|---|---|---|---|---|
| 1 | Velostat + băng đồng (điện cực) | đủ 12 + chuẩn | Phần tử áp trở sandwich | đã có |
| 2 | Khung ốp ngón PETG + vít tiền tải Fp | 3 ngón | Vách cứng + cửa sổ preload | cần chế tạo |
| 3 | R_ref 10 kΩ 0,1% + INA333 (duy nhất — M-16) | 1 bộ | Cầu vi sai + khuếch đại (G sau M-01) | **mua chính hãng (P0)** |
| 4 | CD74HC4067 + MCP6001 + ADS1115 | 2+1+1 | Quét 13 đầu vào + ADC 16-bit | mua (P0) |
| 5 | ESP32-S3 | 1 | Lọc, auto-zero, BLE 20 Hz | đã có |
| 6 | LSM6DS3 (hoặc thay thế có ghi nhận) + SHT30 | 1+1 | Bù nghiêng + log T/RH | mua (P0) |
| 7 | TP4056 + HT7333 + LiPo 3,7 V | 1 bộ | Nguồn đeo cách ly lưới | mua (P0) |
| 8 | Orange Pi 5 Pro (trạm dùng chung) | 1 | Trạm đo + dashboard + báo cáo | **trường đã có** |
| 9 | Giàn: nhôm 2020 + ray + vít me + servo + khớp cứng + lò xo + quả cân | 1 | Kiểm định RAL/GAP/E1–E4 (bỏ phanh — M-20) | dựng (P0/P1) |
| 10 | Load cell 5 kg + HX711 + phantom silicone | 1 | Chuẩn động + tay giả | cell đã có; **HX711 mua ngay** |
| 11 | Thước đo góc + ẩm-nhiệt kế + camera USB | 1 | Góc chuẩn chính + T/RH + đối chứng (P1) | mua |

### 4. Nguyên lý sensing element và trích đặc trưng

**4.1 Cơ chế piezoresistive**
- Velostat: điện trở giảm khi nén; quan hệ **phi tuyến**, có hysteresis, creep, drift, phụ thuộc nhiệt-ẩm.
- Hệ quả: **không** chuyển ADC thành Newton; chỉ dùng đặc trưng **tương đối** và **động**; R(F) đo thật là nút M-01.

**4.2 Bố trí kênh (M-04)**
- 3 ngón × 2 khớp × 2 vách = **12 phần tử** + 1 ô chuẩn = 13 đầu vào ADC, tạo **6 cặp vi sai**.
- Bài tập chuẩn: gập/duỗi từng ngón, chụm, bóp, chạm ngón (thứ tự chốt cùng KTV).

**4.3 Bù drift + nhiệt (bản hẹp)**
- Cặp đối xứng → hiệu `d` giảm thành phần đồng pha; ô chuẩn + auto-zero đầu phiên.
- Nhiệt: **không chương riêng** — log T/RH mọi phiên (SHT30) + 1 đồ thị trôi-vs-T + hệ số r từ dữ liệu C1.8 + trích y văn.
- Cấm chữ "loại bỏ/triệt tiêu hoàn toàn drift" (M-10).

### 5. Luật thường trước, ML đối chứng (thay thế mục "Mô hình học máy" cũ)

- **Luật 0-tham-số gánh chính:** dấu vi sai → hướng; EI/GAP/RAL = phép tính số học + thống kê cổ điển.
- **Thực nghiệm đối chứng duy nhất (P1):** phân loại sự kiện E1–E4 (spike/rung/tuột/bão hòa — định nghĩa ở mức tín hiệu, không dùng từ y khoa) trên dữ liệu giàn + sự kiện giả lập cơ học; phe A luật ngưỡng (scope) vs phe B ML (RF/NN nhỏ); chia test theo phiên; metric chính recall + precision kèm baseline (M-08 chỉ sống lại dưới dạng benchmark đo thật).
- **Cấm:** phân loại MAS/chẩn đoán (M-15), góc từ tín hiệu (M-13), suy nguyên nhân GAP (M-14).

### 6. Đo góc độc lập cho GAP (thay thế mục "Tái tạo 3D" cũ)

- Chuẩn chính: **thước đo góc/goniometer** gắn trên giàn (P0). Đối chứng P1: camera + marker ArUco trên Pi (xử lý ảnh đã test OK).
- Tái tạo 3D đầy đủ + EKF + IMU từng đốt → **hướng phát triển**, không phải mục tiêu giai đoạn này.

### 7. Dashboard và theo dõi từ xa

- Người tập: hướng dẫn bài tập + thanh EI phản hồi tức thời.
- KTV (ngồi nhà): timeline sự kiện E1–E4 + đường cong tuần + **báo cáo PDF tự động**; bấm vào cờ đỏ xem sóng tín hiệu; chuyển file thủ công (USB/nhắn tin) — **không claim cloud/app**.
- Cảnh báo: chỉ khi vượt ngưỡng **và** dữ liệu ở trạng thái hợp lệ (không bị gắn "Nghi vấn").

### 8. Ngân sách (viết đúng phạm vi — M-21)

- Báo cáo ghi: **"thiết bị đeo < 1,5 triệu"** + **"trạm nhà dùng chung"** (Pi của trường, như máy tính KTV).
- Dự toán vận hành E2E < 10M (~5,5M: găng ~1,2M + giàn-đo ~3,2M + dự phòng ~1M) **chỉ nằm ở sổ tay** (`research/notebook/2026-09-29_measurability_M-checklist.md` §5), không vào báo cáo.

### 9. Những câu báo cáo sẽ KHÔNG nói (chống tái phạm M-10..M-15)

| Câu cấm | Thay bằng |
|---|---|
| "Triệt tiêu/triệt để drift/nhiệt" | "Giảm trôi đồng pha; phần dư định lượng qua C1.8" |
| "RAL giảm = bệnh cải thiện" | "RAL là đặc trưng giao thức kiểm định trên giàn" |
| "AI phát hiện co giật/co cứng/MAS…" | "AI gắn cờ sự kiện tín hiệu E1–E4; KTV diễn giải" |
| "Góc quy đổi từ tín hiệu" | "Góc đo độc lập (thước đo góc ± camera)" |
| "GAP do yếu cơ/co cứng" | "GAP ghi nhận chênh lệch; không tự suy nguyên nhân" |
| "AAN hỗ trợ tay người bệnh…" | Mọi câu AAN chỉ viết về phantom |
| "Suy luận INT8 < X ms" (chưa đo) | Chỉ ghi số đo thật + điều kiện đo |

---

## C. CHẾ TẠO MÔ HÌNH VÀ VẬN HÀNH THỬ NGHIỆM

*(Ma trận đo đầy đủ: notebook M-checklist §2; ngưỡng chốt trước khi đo — `research/protocols/08` §7.)*

### 1. Bench điện (M1/M2 + C1.1/C1.2/C1.3/C1.6/C1.7/C1.9)
- R(F) + γ + R² (DMM + quả cân) → **trả lời M-01/M-17** → tính lại G, Vex, chuỗi.
- SNR@1N (scope + log ADS1115); hys lên/xuống; creep 60 s; đồng đều kênh; Vpp 5.000 mẫu (phương pháp tách).

### 2. Lặp lại + drift + đeo (M3/M4/M6 + C1.4/C1.5/C1.8)
- CV nội phiên trên giàn; CV liên ngày tháo/đeo lại (3 ngày); drift 10 ngày 3 lần/ngày + T/RH.
- M6: cửa sổ V_base + 20–30 lần tháo/đeo, đếm phát hiện (đường lui: hạ thành quy trình thao tác).

### 3. Thời gian thực (M5/C1.10)
- fs toàn kênh ≥ 20 Hz (timestamp + scope kẹp DRDY); trễ đầu–cuối ≤ 500 ms (gen phát bước → GPIO mirror).

### 4. Giàn + phantom (RAL/GAP/EI)
- RAL: 10 chu kỳ/nấc, điểm cắt P_complete ≥ 80% (quả cân + đếm).
- GAP: kéo 2 vận tốc (PROM ω₁ ≈ 15°/s) + gập chủ động, góc đọc từ thước đo góc.
- EI: tính offline từ log theo công thức M-25; kiểm nhất quán giữa phiên.

### 5. Đối chứng + camera (P1)
- E1–E4: injector cơ học (búa/lò xo/nới vít) + spec sheet bằng scope → dataset → rules-vs-ML.
- Camera ArUco đối chứng góc vs thước đo góc (sai lệch cho phép vài độ, nếu không đạt thì camera chỉ minh họa).

### 6. Kết quả tích hợp hệ thống (ESP32-S3 ↔ Orange Pi)
- BLE 20 Hz thực đo, tỷ lệ lỗi/khung mất, trễ đầu–cuối, số phiên "Nghi vấn" đúng/sai.

### 7. Kết luận
- Bảng đối chiếu **A.3 → kết quả đo thật** (không ô trống, không claim vượt dữ liệu — M-05).
- Nêu rõ: proof-of-concept trên bench/phantom (+ người đeo ghi theo M-26); chưa thử trên bệnh nhân; không thay thế đánh giá lâm sàng.

### 8. Hướng phát triển
- Tái tạo 3D + EKF + IMU từng đốt; FPC/e-textile; app + cloud; ánh xạ lâm sàng (MAS…) **với đối tác bệnh viện + IRB**.

---

## TÀI LIỆU THAM KHẢO *(verify đầy đủ trước khi nộp — xem `research/evidence/SOURCE_LEDGER.csv`)*

- [ ] Tran M.C. et al., dịch tễ đột quỵ VN, *Global Epidemiology* 2025;9:100199 — đọc toàn văn (số 1,5M = nhóm tự nhân — M-22)
- [ ] Pollock A. et al., Cochrane 2014 — 80%/50% qua Background (← Langhorne 2009…); **không trích Hendricks 2002 cho 80%**
- [ ] Manumeter, *Sensors* 2022 — sai số tự ghi chép 🔵 đối chiếu mức đọc
- [ ] Amin K.R. et al., IEEE OJEMB 2024, DOI 10.1109/OJEMB.2024.3523442
- [ ] Găng từ tính, *Device* 2024 — **không ghi là Gloreha** (M-24)
- [ ] Lin B.-S. et al., *Sensors* 2022 — hệ đa cảm biến co cứng (n = 14, có IRB)
- [ ] ART-Glove, arXiv:2606.16370
- [ ] Liu et al., *A Reconfigurable Data Glove…*, *Engineering* 2024 — **không ghi IROS 2017** (M-24)
- [ ] ironHand 2016 + 2018
- [ ] *Custom Data Gloves* review, arXiv:2405.15417 🔵 xác minh bản IEEE Access nếu trích
- [ ] OTHER 2026, DOI 10.1080/09638288.2026.2643929 🔵 verify
- [ ] Velostat: MIT Media Lab 2012 (đã đọc) + Hopkins, IEEE Sensors J 2020 🔵 verify + bài Sensors & Actuators A 2018 🔵 verify ([18] cũ)
- [ ] Jamar + E-Link (giá/giới hạn) 🔵 bắt buộc đối chiếu lại
- [ ] Tham khảo KTV VLTL-PHCN (ẩn danh, phiếu + ghi chép) — ý kiến chuyên môn, **không** phải nghiên cứu định lượng
- [ ] Đồ nghề: FNIRSI 2C23T (spec theo datasheet/manual + Elektor 2024) — nêu tên máy + spec dùng trong báo cáo, chi tiết ở sổ tay

---

## GHI CHÚ CHO PHIÊN SAU

**Đã thay đổi trong v3.0 (2026-09-29):**
- ✅ Đồng bộ cấu hình đã nộp: cầu vi sai → INA333 → MUX → ADS1115 → ESP32-S3 → BLE → Pi (DEC-HW-005).
- ✅ Áp dụng checklist M-01..M-27: 20 Hz danh định, định nghĩa kênh, INA333 duy nhất, Vex TODO, tách ngân sách, cấm 7 nhóm câu (B.9).
- ✅ AI từ "đầu tàu" → 1 thực nghiệm đối chứng rules-vs-ML (P1); bỏ mục tiêu 3D/MAS/cloud khỏi giai đoạn này.
- ✅ Đồ nghề chốt (DEC-INST-001): 2C23T + DMM phụ + load cell 5 kg (HX711 P0); trần E2E <10M sổ tay-only (DEC-BUDGET-002).
- ✅ Ẩn danh KTV toàn bộ (DEC-ROLE-001); sửa cite epi/Cochrane/IROS/Gloreha (M-22..M-24).
- ✅ Viết lại A1/A2/A3/A4/A6 cho khớp.

**Còn chờ (không đo cho tới khi xong các mục 🔴):**
- [ ] 🔴 Viết công thức EI tường minh (M-25) + chốt 9 ngưỡng `protocols/08` §7.
- [ ] 🔴 Đo R(F) thật → trả lời M-01/M-17 (Vex, G, S, SNR).
- [ ] Ghi rõ người đeo + an toàn (M-26); lấy 5 số INT8 của owner (M-08).
- [ ] Shopping P0: HX711, ADS1115/INA333 chính hãng, SHT30, cân/quả cân, thước đo góc, ẩm-nhiệt kế.
- [ ] Xác minh nốt các cite 🔵 (OTHER, Hopkins, [18], RehabReach, Jamar/E-Link).
- [ ] Viết lại A7/GLOSSARY nếu còn dùng.

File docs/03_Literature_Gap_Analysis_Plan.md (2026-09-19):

# 03 — Kế hoạch phân tích khoảng trống nghiên cứu (2011–2026)

> **Ngày:** 2026-09-19 (lượt rà soát 1) · **Trạng thái:** **ĐÃ CHẠY LƯỢT ĐẦU — CHƯA HOÀN TẤT.**
> Kết quả lượt 1: `research/reviews/2026-09-19_prior_art_novelty_gate1.md` (ma trận §5 đã điền, 24 nguồn mới vào ledger, 3 nguồn `UNVERIFIED` đã xác minh danh tính thư mục).
> **Chưa hoàn tất** vì: (i) cả 24 nguồn mới đều chưa đọc toàn văn (20 `READ_ABSTRACT`, 4 `UNVERIFIED` = mới thấy snippet); (ii) tra bằng sáng chế mới ở mức 1 truy vấn, **chưa** tra theo IPC; (iii) chưa có lane R5 độc lập adjudicate.
> **Lệnh cấm vẫn còn hiệu lực:** chưa được viết bất kỳ câu nào khẳng định "chưa có ai làm".
> **Nguyên tắc chống ảo giác:** "không tìm thấy trong một truy vấn" chỉ cho phép ghi `UNVERIFIED`, **không** chứng minh "chưa có ai làm". Một nguồn chỉ vào `research/evidence/SOURCE_LEDGER.csv` sau khi đã xác minh tiêu đề/tác giả/venue/năm/DOI/URL **và** đọc được đoạn văn hỗ trợ đúng claim.

---

## 1. Mục tiêu

Xác định **mức prior art** của 4 ứng viên novelty của đề tài găng tay, theo thứ tự quan trọng:

| Ưu tiên | Ứng viên novelty | Câu hỏi prior-art cần trả lời |

|---|---|---|
| **A (cao nhất)** | Cảm biến **hướng** qua vách khung cứng: dùng áp lực lên vách cơ khí để mã hóa **hướng chuyển động của lóng ngón**, không dùng IMU | Đã có ai dùng khung cứng + piezoresistive để suy hướng khớp chưa? Bằng sáng chế nào? |
| **B** | Suy luận hướng khớp từ trường lực rời rạc → **tái tạo bàn tay 3D** không cần IMU | Có công bố nào tái tạo pose không dùng IMU/camera? Sai số bao nhiêu? |
| **C** | **Longitudinal monitoring** chức năng bàn tay tại nhà giữa các lần tái khám, có **tự kiểm tra độ tin cậy** | Đã có hệ thống nào theo dõi bàn tay tại nhà theo tuần và tự báo "dữ liệu không đáng tin"? |
| **D** | Hạ chi phí so với dynamometer/E-Link bằng vật liệu piezoresistive giá rẻ | Ngưỡng giá của các giải pháp hiện có; có sản phẩm thương mại nào < 50 USD? |

**Điều kiện để A được xem là "chưa bị chiếm":** phải tìm và đọc được công bố/sáng chế gần nhất theo cùng nguyên lý, rồi chỉ ra được **khác biệt cụ thể**, không phải chỉ "khác về ứng dụng".

---

## 2. Mười nhóm chủ đề tìm kiếm

| # | Nhóm | Truy vấn gợi ý (tiếng Anh) | Trạng thái |
|---|---|---|---|
| 1 | Găng tay cảm biến cho phục hồi chức năng | `smart glove stroke rehabilitation hand function monitoring` · `data glove piezoresistive hand therapy` | ĐÃ LÀM MỘT PHẦN — `SRC-SMARTGLOVE-REVIEW-2026` (đã verify), `SRC-CUSTOMGLOVE-REVIEW-2024`, `SRC-VMG30-APPLSCI-2023`. Chưa rà hết dòng găng PHCN thương mại. |
| 2 | Đo **hướng** lực / mô-men bằng vật liệu áp điện trở | `directional force sensing piezoresistive glove` · `shear force glove sensor` | ĐÃ LÀM — KẾT QUẢ BẤT LỢI: nguyên lý vách + piezoresistive suy ra hướng đã có từ 2014-2015 (`SRC-SIDEWALL-PIEZO-2015`, `SRC-INTERLOCKED-MICRODOME-2014`). Phải đọc toàn văn. |
| 3 | Tái tạo pose bàn tay không dùng camera/IMU | `hand pose reconstruction without IMU` · `glove kinematic reconstruction force sensor` | ĐÃ LÀM MỘT PHẦN — đã có găng suy pose không IMU bằng dải cách tử/quang (`SRC-GRATING-GLOVE-2021`) và cảm biến giãn (`SRC-STRETCH-GLOVE-2024`). "Không dùng IMU" không còn là novelty tự thân. |
| 4 | Khung cứng / exoskeleton mềm và cảm biến tích hợp | `rigid exoskeleton frame finger force sensing` · `finger segment displacement sensor` | ĐÃ LÀM — KẾT QUẢ BẤT LỢI: ART-Glove 2026 = vỏ cứng khớp nối + 16 bề mặt chức năng phủ da áp điện trở (`SRC-ARTGLOVE-2026`), nhưng đo góc bằng encoder. Prior art phần cứng gần nhất; phải đọc toàn văn. |
| 5 | Theo dõi tại nhà sau đột quỵ | `home monitoring upper limb stroke wearable longitudinal` | ĐÃ LÀM MỘT PHẦN — `SRC-LOWCOST-GLOVE-2006` (extended monitoring + functional hand assessment, 2006), `SRC-MANUMETER-RCT-2022`, `SRC-MULTITOUCH-APP-2021`. Khoảng trống C chỉ còn ở giao điểm hẹp (review §2.3). |
| 6 | Thang đo lâm sàng & MDC | `Fugl-Meyer ARAT minimal detectable change upper extremity` | ĐÃ LÀM MỘT PHẦN — đã xác minh `SRC-STEF-MDC-2026` (ICC 0,98; MDC95 = 12,7 điểm; n=53). "MDC của ARAT ~4 điểm" VẪN UNVERIFIED. |
| 7 | Lực ngón và chức năng | `finger force grip pinch correlation Fugl-Meyer` | CÒN NỢ — `SRC-RCT-FORCEHAND-2024`, `SRC-FINGERUSE-2023` mới READ_ABSTRACT; chưa trích được số tương quan nào. |
| 8 | Đặc tính vật liệu Velostat | `Velostat characterization hysteresis creep drift pressure sensor` | CHƯA LÀM LẠI — và ĐÂY LÀ CHỐT CHỐT của mô hình docs/02 §5.5 (cần γ, R(p), R_max(ADC+MUX) để mở/đóng cửa sổ preload) — `SRC-HOPKINS-2020-VELOSTAT-SOCKET` và `SRC-HOPKINS-2020-IEEEJS` là hai dòng của cùng một bài (phải gộp); số liệu hysteresis/creep phải lấy từ bản gốc. |
| 9 | Tự kiểm tra/hiệu chuẩn cảm biến | `sensor self-validation reference cell drift compensation` · `self-calibration piezoresistive` | ĐÃ LÀM MỘT PHẦN — thêm bằng chứng đọc hai bên để tách thành phần đã có tiền lệ (`SRC-OPENPAD-FINGER-2020`) → càng không được claim cặp đối xứng là mới. |
| 10 | Edge-AI cho thiết bị đeo y tế | `INT8 quantization wearable healthcare NPU on-device inference` | CHƯA LÀM — cần một lượt riêng cho RKNN/INT8 trên RK3588 và các công bố wearable INT8 y tế. |
| 11 | Bằng sáng chế liên quan | `patent glove force sensor hand rehabilitation monitoring` (Google Patents, WIPO, USPTO) | ĐÃ ĐỌC 2 HỒ SƠ (2026-09-19): US20150233779A1 **Abandoned**; CN116954366A **Pending** (SEU, 20 phan tu ap tro). CHƯA HOÀN TẤT: tra cứu theo phân loại qua Google Patents XHR **bất khả thi trong môi trường này** (xem §7). → cần Espacenet CQL / Lens / PatentsView với tài khoản. `SRC-TW201533608A-PRESSUREGLOVE`, `SRC-CN116954366A-ARRAYGLOVE` |
| 12 | Đề tài trong nước đã có | `đồ án găng tay cảm biến phục hồi chức năng` · các đề tài ViSEF/ISEF/thi KHKT đã đạt giải | ĐÃ PHÁT HIỆN RỦI RO — 3 hàng xóm trong nước đều là máy tập: `SRC-VNM-HS-GLove-2026` (HS Lâm Đồng, giải nhất cấp tỉnh 2026 — gần nhất về mức học sinh), `SRC-VNM-ANNAM-2022`, `SRC-VNM-TL-GLOVE-2026`. Mới có báo chí, chưa có báo cáo gốc. |
| 13 | **Găng tập có trợ lực / AAN / an toàn khi co cứng** (mở rộng theo đề xuất 2026-09-19) | `assist-as-needed soft robotic glove EMG stroke` · `intention detection hand exoskeleton safety torque limit` · `spasticity velocity-dependent resistance robotic assessment` | ĐÃ LÀM MỘT PHẦN (lượt 1) — 16 dòng vào ledger; kết quả: **hướng này KHÔNG còn trống** (`SRC-IRONHAND-2018`, `SRC-AAN-EMG-2024`, `SRC-THUMB-AAN-2026`) + trùng 2 dự án VN. Bắt buộc đọc toàn văn 4 bài nền + tra IPC `A61H1/02`, `A61H3/01` trước khi chủ dự án chốt `DEC-SCOPE-002` |

---

## 3. Nguồn gốc đã có (từ giai đoạn trước — phải đọc lại toàn văn)

Các tài liệu dưới đây đã **gặp trong quá trình tra cứu** nhưng chưa được đưa vào `SOURCE_LEDGER.csv` với trạng thái `READ_FULL`. Trước khi trích dẫn, phải đọc toàn văn và ghi lại số trang/bảng số cụ thể.

- Systematic review: *AI-based smart glove for hand movement recognition and rehabilitation monitoring* (Springer, 2026 — 101 bài 2011–2025). 🔵 xác minh lại tạp chí, số, DOI.
- *Wearable technology to capture arm use of stroke survivors in home and community settings* (medRxiv 2023 / PMC9901039).
- *Tracking Upper Limb Motion via Wearable Solutions* — systematic review (JMIR 2024).
- *Occupational Therapy at Home E-Rehabilitation (OTHER)* — DOI 10.1080/09638288.2026.2643929, PMID 41918405.
- Amin K.R. et al., *Remote Monitoring for the Management of Spasticity: Challenges, Opportunities and Proposed Technological Solution* — IEEE OJEMB, early access 30/12/2024, DOI 10.1109/OJEMB.2024.3523442. (Lưu ý: đối tượng là **spasticity**, không phải trực tiếp chức năng bàn tay → chỉ dùng để chứng minh **khoảng trống chung** về theo dõi giữa các lần tái khám.)
- Zhu lab (UCLA), *A Glove-based System for Studying Hand-Object Manipulation* (IROS 2017) — 15 IMU + 6 cảm biến Velostat lực tiếp xúc. **Prior art gần nhất, phải differentiate rõ.**
- *A Reconfigurable Data Glove for Reconstructing Physical and Virtual Grasps* (2023) — mạng IMU + Velostat.
- *Development of an Instrumented Glove for Palmar Pressure Assessment in Kayakers* (Sensors 2026) — Velostat trong găng, bối cảnh thể thao.
- *Design of a flexible data glove for gesture recognition* (2025) — mảng piezoresistive 5×4, nhận dạng cử chỉ.
- Hopkins M. et al., đặc tính Velostat — IEEE Sensors Journal 2020 (🔵 xác minh lại tên bài/DOI).
- *Effect of task-oriented training assisted by force feedback hand rehabilitation robot on finger grasping function in stroke patients with hemiplegia* (2024, PMC11092254) — RCT, cho thấy lực bóp/AROM/FMA-Hand/ARAT cải thiện; dùng làm bằng chứng **lực ngón có ý nghĩa lâm sàng**.
- *Quantitative measurement of finger usage in stroke hemiplegia using ring-shaped wearable devices* (2023, PMC10242812) — tỷ lệ sử dụng ngón tương quan với FMA-UE/ARAT/STEF.

---

## 4. Quy trình thực hiện

1. Với mỗi nhóm chủ đề, chạy tối thiểu **3 truy vấn khác cách diễn đạt** (thuật ngữ chuyên ngành, thuật ngữ thương mại, thuật ngữ bằng sáng chế).
2. Log mọi truy vấn vào `research/queries/QUERY_LOG.jsonl` bằng `scripts/research_log.py` (kèm mục đích và kết luận đạt/không đạt).
3. Chỉ ghi nguồn vào `SOURCE_LEDGER.csv` khi đã xác minh **tiêu đề + tác giả + venue + năm + DOI/URL** và **đoạn văn hỗ trợ đúng claim**.
4. Điền vào **ma trận theo dõi** dưới đây, mỗi dòng một công bố/sáng chế.
5. Kết thúc: viết một đoạn **"prior art gần nhất và khác biệt cụ thể"** cho từng ứng viên novelty. Nếu không tìm được khác biệt → **hạ mức novelty**, không được giữ nguyên câu claim.

> **Cập nhật 2026-09-19 (2):** Nhóm 13 được mở vì chủ dự án đề xuất thêm hướng "tập chủ động có trợ lực". Kết quả + phương án xử lý: `research/reviews/2026-09-19_active_assisted_scope_options.md`. Trạng thái: PROPOSED — chờ `DEC-SCOPE-002`.

## 5. Ma trận theo dõi (điền dần)

Bản điền đầu tiên (lượt 1) nằm trong **`research/reviews/2026-09-19_prior_art_novelty_gate1.md` §2.1–§2.4**, đúng 9 cột của mẫu, gồm 14 công bố/bằng sáng chế/nguồn trong nước.

| ID | Nguồn | Loại | Đo gì | Cảm biến | Đối tượng | Theo dõi dọc? | Tự kiểm tra lỗi? | Khác biệt với đề tài |
|---|---|---|---|---|---|---|---|---|
| → xem file review §2 (không điền trùng ở đây để tránh hai bản lệch nhau) | | | | | | | | |

## 6. Ngưỡng ra quyết định

- Nếu tìm thấy **một công bố hoặc bằng sáng chế đã làm đúng** "khung cứng + piezoresistive → suy hướng khớp + tái tạo 3D": **hạ novelty A xuống mức "cải tiến"**, dồn trọng tâm sang C (longitudinal + self-validation).
- Nếu tìm thấy hệ thống theo dõi bàn tay tại nhà theo tuần đã có sản phẩm: **hạ novelty C**, dồn sang A.
- Nếu **cả A và C đều bị chiếm**: dừng, báo thẳng, không viết báo cáo như thể còn mới.

### 6.1 — Áp dụng ngưỡng sau lượt rà soát 1 (2026-09-19)

| Nhánh | Điều kiện trong §6 | Đã xảy ra chưa | Hệ quả đang áp dụng |
|---|---|---|---|
| Hạ A | Có **một** công bố/patent làm **đúng** "khung cứng + piezoresistive → suy hướng khớp → tái tạo 3D" | ❌ chưa (ART-Glove 2026 đúng vỏ cứng + da áp điện trở nhưng đo góc bằng encoder; chưa đọc toàn văn) | A bị **hạ một bậc**: từ "nguyên lý vật lý/cơ khí mới" → "cải tiến cấu hình + phương pháp lập luận", vì nguyên lý phần tử vách→hướng đã có từ 2014–2015. Chưa rơi hẳn vào nhánh "dồn sang C". |
| Hạ C | Đã có **sản phẩm** theo dõi bàn tay tại nhà theo tuần | ⚠️ một phần: nguyên mẫu học thuật từ 2006 + app đã chuẩn hóa MDC (2021); chưa thấy sản phẩm thương mại cho PHCN đột quỵ tại nhà | Chưa kích hoạt. Nhưng **cấm** mọi câu "hệ thống đầu tiên theo dõi tại nhà". |
| Dừng | **Cả** A và C đều bị chiếm | ❌ | Tiếp tục. GATE A và GATE C vẫn là hai cổng quyết định. |

**Bản novelty đề xuất sau lượt 1** (chờ `DEC-NOV-001` + lane R5):

- **A** = cải tiến cấu hình + cách lập luận hướng khớp; bắt buộc trích `SRC-SIDEWALL-PIEZO-2015`, `SRC-INTERLOCKED-MICRODOME-2014`, `SRC-ARTGLOVE-2026`, `SRC-CN116954366A-ARRAYGLOVE`.
- **B** = phát biểu lại: "dấu gập/duỗi suy ra **chỉ** từ mẫu kích hoạt trên vách có preload — không encoder, không IMU, không camera".
- **C** = **ứng viên chính**, giới hạn trong giao điểm hẹp: lực hướng + khung MDC/ICC + cờ từ chối kết luận, dùng tại nhà giữa hai lần tái khám.
- **D** = chỉ được nói "rẻ hơn" khi có bảng giá BOM thật so với `SRC-TACTILEGLOVE-II` / Jamar / E-Link.

## 7. Kiểm soát bằng sáng chế — phương pháp đã dùng, thất bại đã gặp, lối thoát (2026-09-19)

**Đã làm (thật):** đọc trang Google Patents của 2 hồ sơ và ghi lại **CPC thực tế** của chúng:

| Hồ sơ | Trạng thái pháp lý | CPC được gán |
|---|---|---|
| `US20150233779A1` / `TW201533608A` — "Gloves with pressure sensors" (Waltop International Corp) | **Abandoned** (không còn hiệu lực) | G01L1/20, G01L1/22, G01L1/205, G01L5/009, G01P15/00, G01C19/02 |
| `CN116954366A` — "Touch perception glove based on sensor array" (Đông Nam University) | **Pending** | **G06F3/014** (găng dữ liệu), A41D19/00 |

**Kết luận về phương pháp (quan trọng hơn kết luận về nội dung):** các bằng sáng chế "găng áp trở" được phân loại ở
**G06F3/014 / A41D19/00 / G01L1-20x**, chứ không nằm ở A61B5/A61H. → Bộ mã truy vấn cũ của file này
(A61B5/11, A61B5/22, A61B5/10, G01L1/14, A61H1/02, A61H3/01) là **thiếu**; phải thêm
`G06F3/014`, `A41D19/00`, `G01L1/20`, `G01L1/205`, `G01L5/009` rồi mới được nói đến "đã rà bằng sáng chế".

**Thất bại cần ghi lại để phiên sau khỏi làm lại:** trong môi trường làm việc này **không** truy vấn theo phân loại qua Google Patents được:
- `https://patents.google.com/xhr/query?url=q%3D…%26cpc%3DA61H3%2F01…` trả về `total_num_results: 0` ở 3 biến thể (có/không `status`, có/không `language`);
- một biến thể khác trả `HTTP 500`. Trong khi đó trang chi tiết từng bằng sáng chế (`/patent/<id>/en`) đọc bình thường.
→ Để hoàn tất tra cứu theo phân loại, cần **Espacenet CQL** (`cpc=(G06F3/014) and txt=(piezoresistive glove)`), **Lens.org** hoặc **PatentsView API** —
cả ba đều **cần tài khoản/API key**, không làm được trong phiên này. **Không** được viết "đã tra cứu IPC" trong bất kỳ tài liệu nộp nào cho tới khi một trong ba đường đó chạy xong.

**Hệ quả cho hồ sơ (nên nói thẳng, vì đây là điểm trung thực chứ không phải điểm yếu):** mục "kiểm soát bằng sáng chế" trong đề tài ở mức
*rà soát sơ bộ 2 hồ sơ gần nhất + ghi rõ giới hạn phương pháp*, không phải một cuộc tra cứu FTO đầy đủ.

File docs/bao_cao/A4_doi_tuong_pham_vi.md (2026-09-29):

# A.4 — Đối tượng và phạm vi nghiên cứu

- **Đối tượng nghiên cứu:** Di chứng liệt/yếu tay sau đột quỵ và nhu cầu theo dõi chức năng vận động bàn tay tại nhà; hạn chế của các công cụ đánh giá lâm sàng trong theo dõi liên tục; đặc tính kỹ thuật của vật liệu Velostat và phương pháp xây dựng phần tử cảm biến từ vật liệu này.

- **Đối tượng thực nghiệm:** Găng 3 ngón + chuỗi đo vi sai + trạm biên + giàn kiểm định + mô hình tay giả; thu thập, xử lý và phân tích tín hiệu; trích xuất EI/GAP/RAL; thực nghiệm đối chứng luật-thường-vs-học-máy trên sự kiện giả lập.

- **Phạm vi kỹ thuật:** 12 phần tử + ô chuẩn + 1 IMU; cầu vi sai → INA333 → 2×CD74HC4067 → MCP6001 → ADS1115 → ESP32-S3 → BLE → Orange Pi 5 Pro (trạm dùng chung); dashboard + báo cáo tuần; AAN chỉ demo trên phantom.

- **Người đeo (TODO M-26):** ghi rõ ai đeo (kể cả thành viên nhóm), khi nào, biện pháp an toàn (nguồn pin, cách ly lưới, không lực tác động lên người).

- **Giới hạn:** không chẩn đoán; không can thiệp vận động trên người; không thay thế đánh giá lâm sàng; không claim hiệu quả lâm sàng; không thực nghiệm trên bệnh nhân trong giai đoạn này.

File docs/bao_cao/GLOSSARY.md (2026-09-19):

# GLOSSARY — Định nghĩa thuật ngữ dùng nhất quán trong báo cáo
# (Cập nhật 2026-09-13 — Găng tay theo dõi chức năng bàn tay sau đột quỵ; phần cứng ESP32-S3)

---

## Hệ thống phân cấp cảm biến

| Cấp | Tên gọi trong báo cáo | Thành phần | Ghi chú |
|---|---|---|---|
| Vật liệu | **vật liệu piezoresistive Velostat** | Film polyolefin tẩm carbon | KHÔNG gọi là "cảm biến Velostat" |
| Điện cực | **điện cực copper tape** | Băng đồng dẫn điện | Tạo tiếp xúc điện |
| Phần tử cảm biến | **sensing element** | Velostat + copper tape + cấu trúc sandwich + lớp cơ khí giữ hình học | Do tác giả chế tạo |
| Cặp phần tử | **cặp sensing element đối xứng** | 2 sensing element trên 2 vách đối diện của cùng khung | Dùng để đọc vi sai (hiệu), triệt thành phần drift đồng pha |
| Hệ thống đo | **mảng sensing element** | 12–24 sensing element trên khung găng in 3D | Bố trí theo bảng trong `docs/04_Hardware_Architecture.md` |
| Hệ thống hoàn chỉnh | **hệ thống cảm biến áp lực bàn tay** | Mảng + CD74HC4067 + ESP32-S3 + firmware | Toàn bộ phần đo, chưa gồm xử lý biên |
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

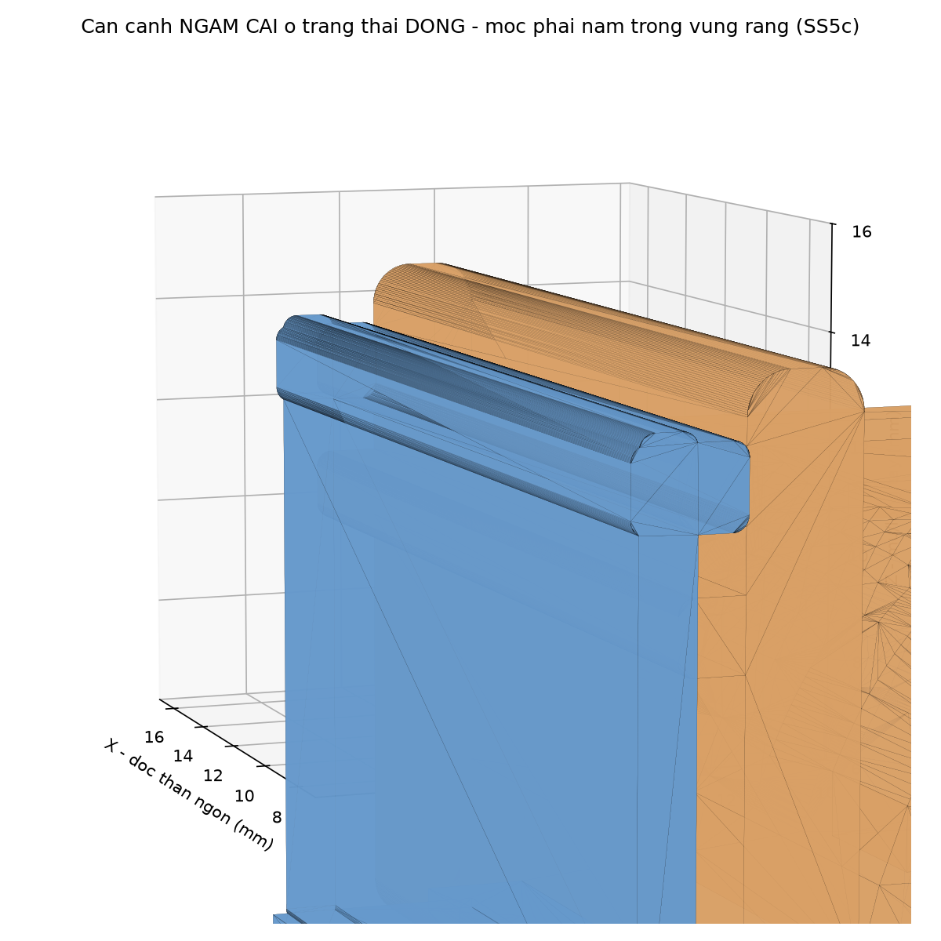
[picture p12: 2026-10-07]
hardware/cad/finger_shell_hinge/out/renders/08_latch_closeup.png

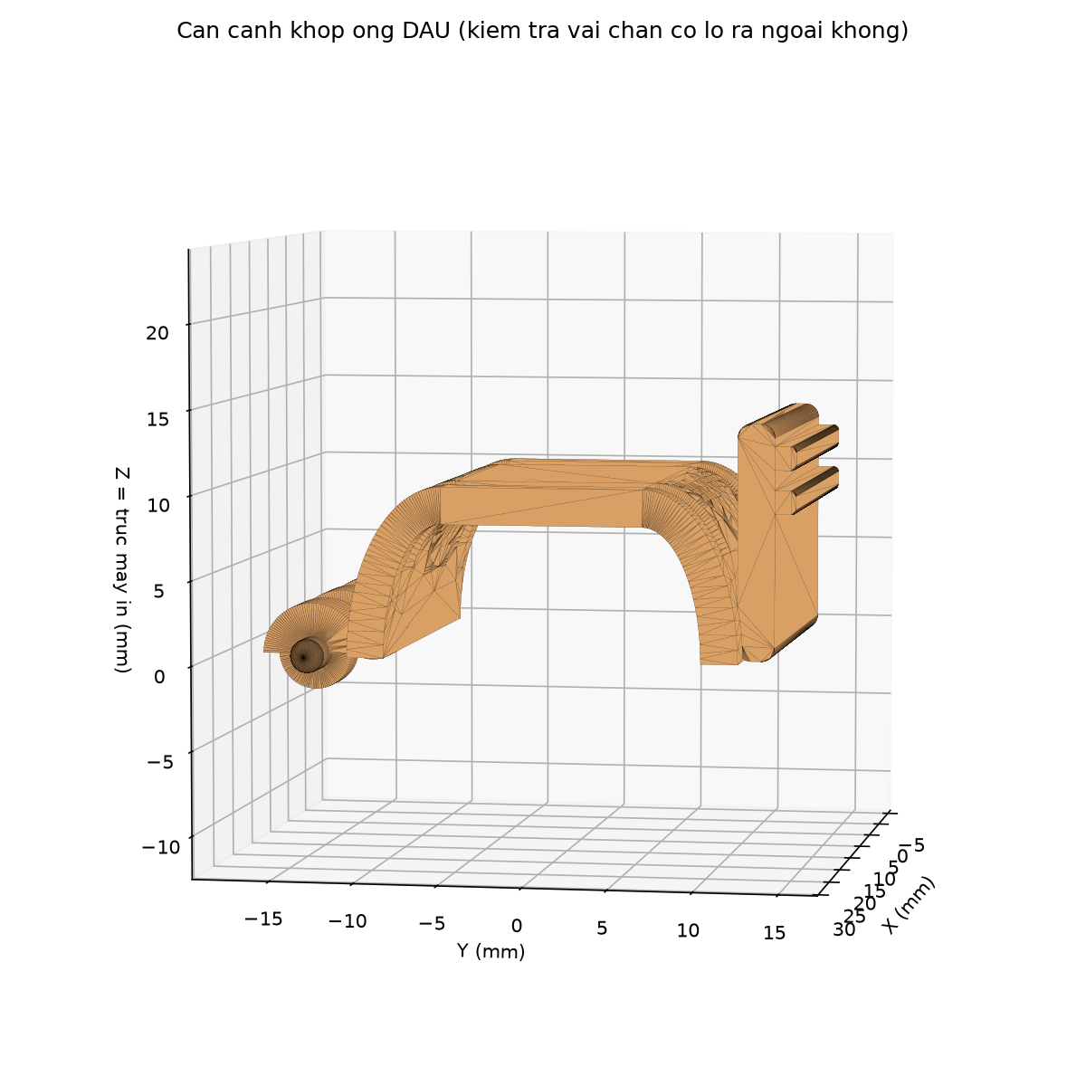
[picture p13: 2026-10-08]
hardware/cad/finger_shell_hinge/out/renders/16_top_knuckle_closeup.png

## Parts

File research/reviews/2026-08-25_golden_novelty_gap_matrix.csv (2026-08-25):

card_id | paper_or_source_id | year | measurement_target | sensor_and_reference | direct_failure_or_limitation | gap_hypothesis_to_test | read_status | golden_novelty_relevance
GM-01 | SRC-ZHANG-2025-3DGRF | 2025 | 3D-GRF | CapSense+IMU; force plates | Generic low-cost 3D-GRF regression already demonstrated | Do not claim generic 3D-GRF novelty; test longitudinal attribution | READ_FULL | Prior-art boundary
GM-02 | SRC-OLUGBON-2025-VGRF | 2025 | vGRF | Pressure contacts+IMU; stated reference in preprint | Drift/generalization are named; contact geometry used to reduce magnitude dependence | Does multi-session sensor-state attribution outperform contact/IMU baseline? | READ_FULL_PREPRINT | Close mechanism
GM-03 | SRC-YAMAGUCHI-2023-3DGRF | 2023 | 3D-GRF | Four triaxial sole sensors; force plate | Pressure-only horizontal force inference is limited | Velostat pressure-only must not assume Fx/Fy observability | READ_FULL | Gold-standard architecture warning
GM-04 | SRC-ROUSE-2023-INSOLE-RETEST | 2023 | vGRF/COP | Wireless pressure insole; force plate | Systematic vGRF and ML-COP differences despite reliability | Separate agreement bias from repeatability/change detection | READ_FULL | Metric design
GM-05 | SRC-BLIN-2022-COP | 2022 | COP | Moticon insole; force plate/mocap | Task-matched calibration and force/active-cell dependence | Detect calibration/task mismatch as measurement-state shift | READ_FULL | Hidden variable
GM-06 | SRC-FUCHS-2024-REDUCED-COP | 2024 | COP | 99-sensor reference with simulated layouts | Accuracy varies by gait, direction, number/layout | Optimize layout for longitudinal MDC/false alerts, not one-task RMSE | READ_FULL | Hardware-hypothesis coupling
GM-07 | SRC-WEIZMAN-2019-BENCHMARK | 2019 | Force/COP | Smart insole/Pedar; Kistler force plate | Relative insole position affects accuracy | Treat fit/placement as a measured perturbation | READ_FULL | Hidden variable
GM-08 | SRC-DEFAZIO-2021-VELOSTAT | 2021 | Pressure/gait | Velostat matrix; bench characterization | Hysteresis/time-history motivates correction | Measure cell state/residual drift rather than assert correction | READ_FULL | Sensor mechanism
GM-09 | SRC-JUNG-2026-PIEZO-SHEAR | 2026 | Pressure/shear | Tilted piezoresistive modules; treadmill | Initial drift/stabilization under cycles | Compare normal-pressure-only and sensor-state signals under loading history | READ_FULL | Failure mechanism
GM-10 | SRC-HU-2023-VELOSTAT | 2023 | Gait phases | 174-cell Velostat; phase reference | Cell outputs change at differing rates and crosstalk needs mitigation | Low-cost matrix must characterize crosstalk/cell heterogeneity before kinetic inference | READ_FULL | Velostat boundary
GM-11 | SRC-PARKER-2023-XSENSOR | 2023 | Pressure/contact area | XSENSOR; two-day bench loads | Creep/protocol-specific suitability | Use reference-load sentinel to estimate measurement health across sessions | READ_FULL | Control design
GM-12 | SRC-LIU-2025-RELIABILITY | 2025 | Plantar-pressure metrics | Embedded in-shoe system; two sessions | Reliability and MDC differ by trajectory/distance | Change alert must exceed context-specific MDC, not only ML threshold | READ_FULL | Decision metric
GM-13 | SRC-SCHELTINGA-2025-IMU-DAYS | 2025 | IMU-vGRF | 3 IMUs; outdoor three days | Session effect confounds placement with natural variability | Use controlled perturbations plus reference to identify session components | READ_FULL | Direct conceptual neighbor
GM-14 | SRC-SANTOS-2024-REVIEW | 2024 | Insole technology review | Review | Real-world/longitudinal validation and calibration standardization lacking | Narrow a testable standardized measurement-integrity protocol | READ_FULL | Landscape support only
GM-15 | SRC-SCIREP-2025-INDIVIDUALITY | 2025 | Plantar-pressure individuality | Pressure platform; repeated healthy trials | Intra-individual variation matters for subsequent sessions | Personal baseline needs uncertainty/MDC not population threshold | READ_FULL | Longitudinal metric
GM-16 | SRC-NPJPD-2026-LONGITUDINAL | 2026 | Wearable digital mobility | Wrist wearable; longitudinal cohorts | Within-person change needs reliability and non-disease comparison | Borrow evaluation logic but not disease/device claims | READ_FULL | Endpoint framework
GM-17 | CAND-PEERJ-2024-16SENSOR-IMU | 2024 | vGRF and AP-GRF | 16 resistive sensors+IMU; treadmill | GRF accuracy varies substantially between participants despite LOSO validation | Test session/context splits separately from LOSO; do not infer longitudinal fidelity from LOSO alone | READ_FULL | Candidate baseline
GM-18 | SRC-ELSTUB-2022-SAMPLING | 2022 | Peak force | Pedar; sampling-rate manipulation | Sampling/battery trade-off changes peak-force error | Measure Mega/multiplex temporal-error budget on actual hardware; do not transfer Pedar results | READ_FULL | Embedded constraint
GM-19 | CAND-XSENSOR-2025-DRIFT | 2025 | Pressure reliability | Commercial system; controlled walking | Subtle midfoot changes may fall inside test-retest error | Use region/task-specific minimum detectable change | SEARCH_EXCERPT | Candidate limitation
GM-20 | CAND-OUTDOOR-2026-CONDITION | 2026 | Walking-condition classification | IMU+pressure; controlled outdoor conditions | IMU outperformed pressure-only condition classification; ecological generalization remains a stated concern | Use context estimation as a quality-control input, not evidence of biological change | READ_FULL | Potential S/E observation channel

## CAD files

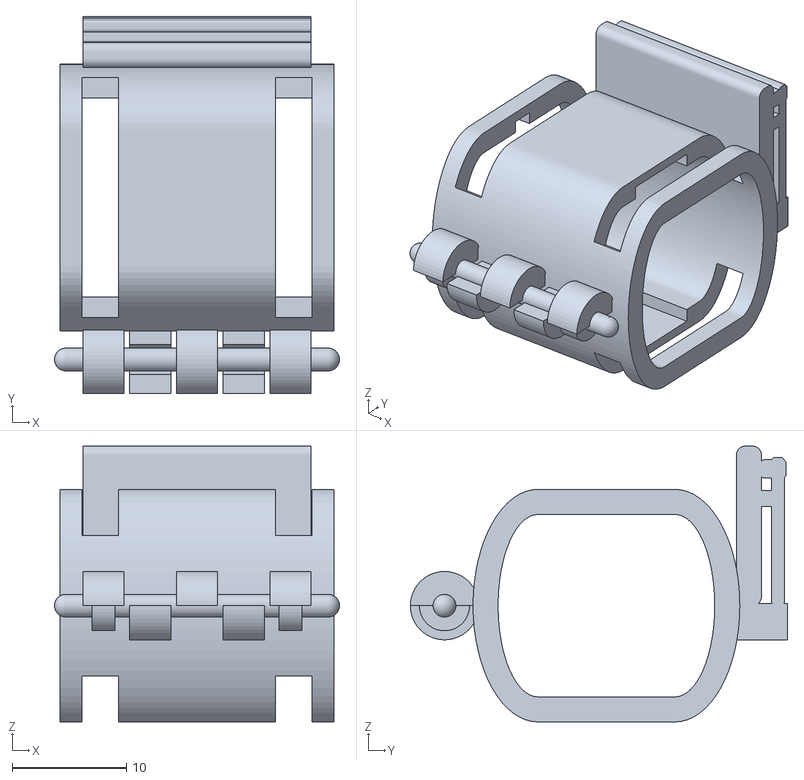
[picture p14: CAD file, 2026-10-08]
hardware/cad/finger_shell_hinge/out/scad/assembly_closed.stl
25.0 x 33.1 x 24.2

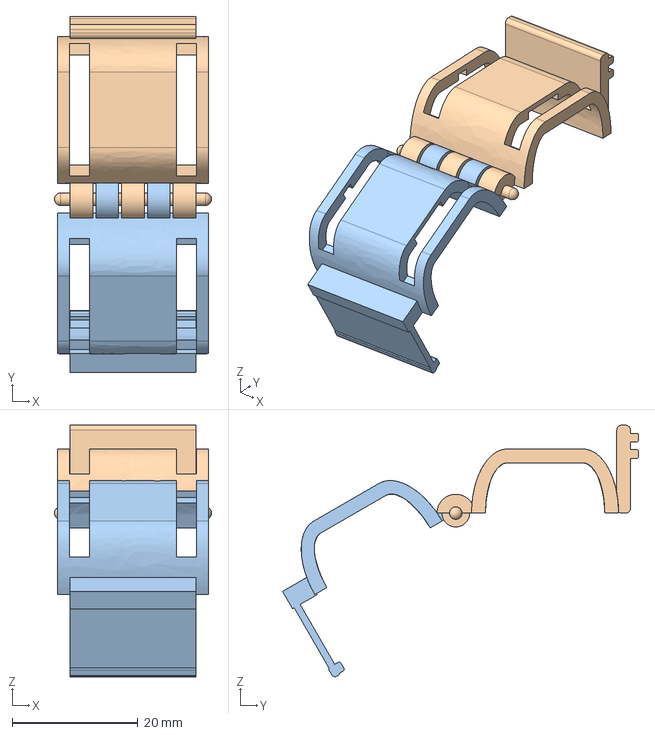
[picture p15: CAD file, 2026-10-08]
hardware/cad/finger_shell_hinge/out/assembly_open.step
25.0 x 56.6 x 40.0 mm
top_shell_dorsal
bottom_shell_palmar

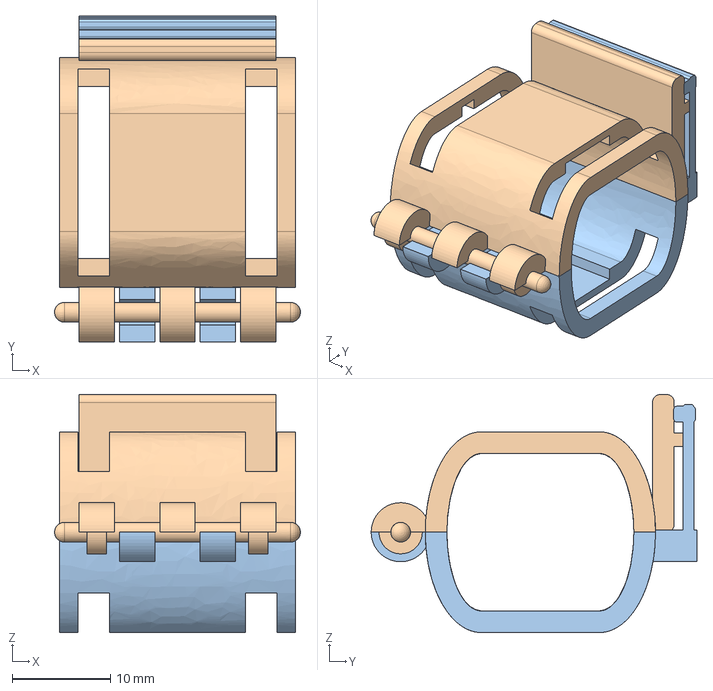
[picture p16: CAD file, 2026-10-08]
hardware/cad/finger_shell_hinge/out/assembly_closed.step
25.0 x 33.1 x 24.2 mm
top_shell_dorsal
bottom_shell_palmar

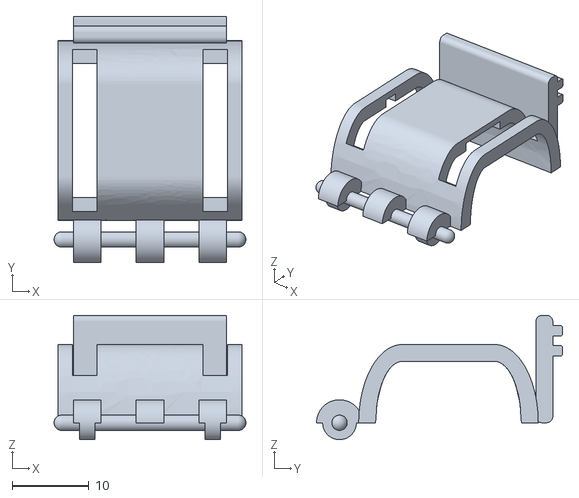
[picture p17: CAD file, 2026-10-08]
hardware/cad/finger_shell_hinge/out/assembly_open__top.stl
25.0 x 32.1 x 16.2

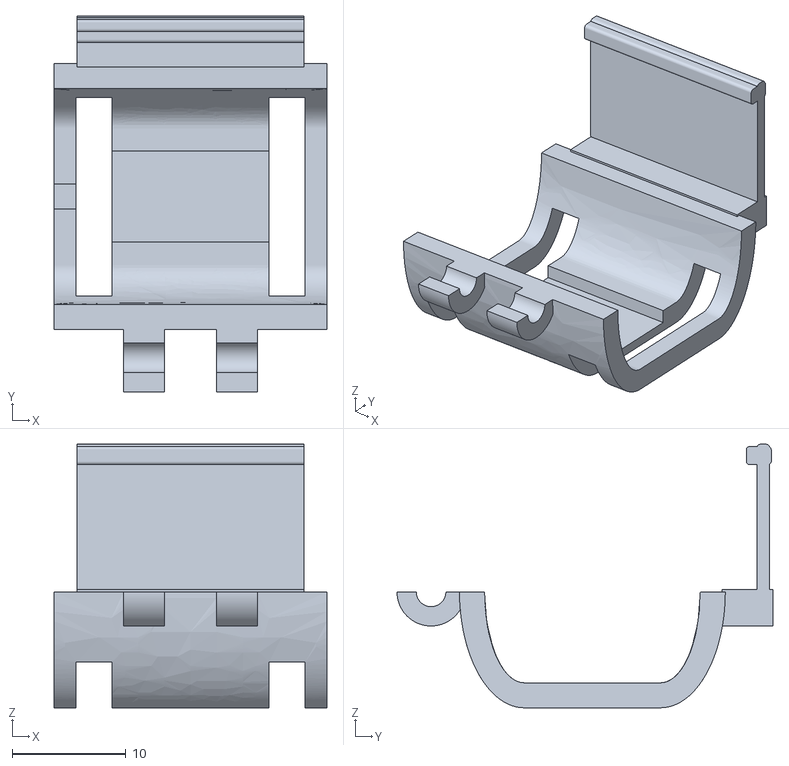
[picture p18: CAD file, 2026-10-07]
hardware/cad/finger_shell_hinge/out/assembly_closed__bottom.stl
24.0 x 33.1 x 23.2

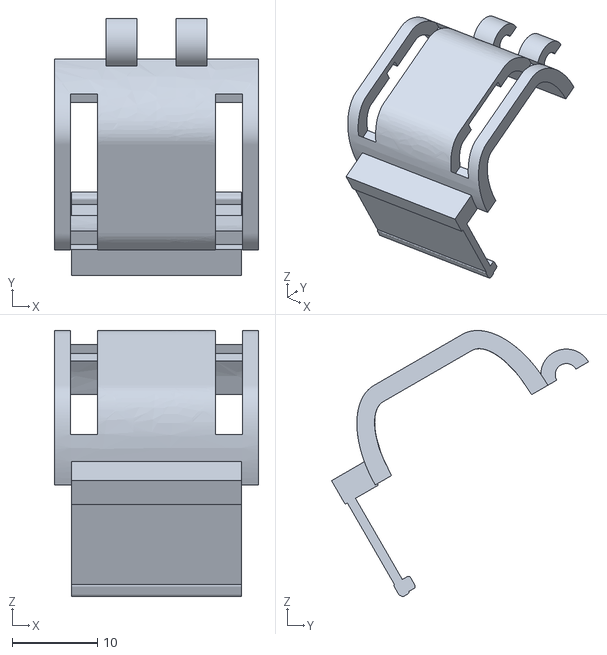
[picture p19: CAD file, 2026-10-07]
hardware/cad/finger_shell_hinge/out/assembly_open__bottom.stl
24.0 x 30.2 x 31.2

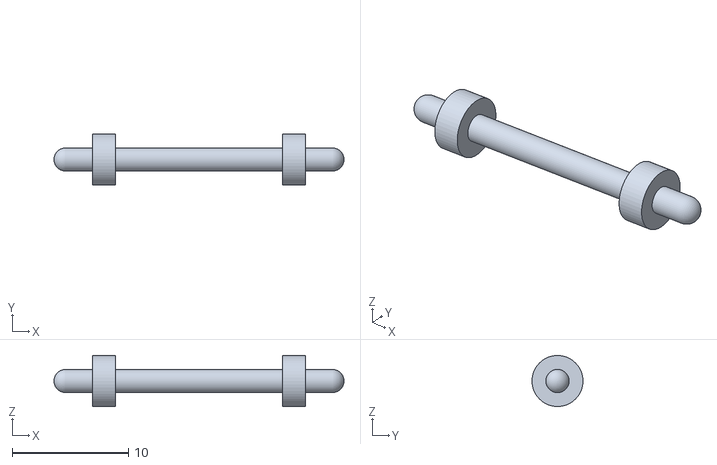
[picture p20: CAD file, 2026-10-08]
hardware/cad/finger_shell_hinge/out/scad/hinge_pin.stl
25.0 x 4.40 x 4.40

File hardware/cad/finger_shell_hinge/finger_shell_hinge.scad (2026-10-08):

// =====================================================================
// Khung ốp 1 đốt ngón tay — cơ chế BẢN LỀ + NGÀM CÀI (mã OpenSCAD)
// =====================================================================
// Tương ứng 1-1 về tham số & hình học với bản CadQuery đã chạy & xuất
// STEP/STL trong repo: hardware/cad/finger_shell_hinge/finger_shell_hinge.py
// (xem out/*.step, out/renders/*.png).
//
// LÝ DO CÓ CẢ 2 BẢN (CadQuery .py VÀ OpenSCAD .scad này):
//   - Sandbox dựng thiết kế này KHÔNG có apt/internet tới kho Debian, nên
//     KHÔNG cài được OpenSCAD lẫn FreeCAD GUI ở đó. Bản .py (CadQuery, cài
//     qua pip, dùng chung lõi hình học Open CASCADE với FreeCAD) là bản ĐÃ
//     CHẠY VÀ KIỂM TRA HÌNH HỌC THẬT trong sandbox đó (xuất STEP/STL, dựng
//     ảnh xem nhanh trong out/renders/).
//   - File .scad này viết tay theo đúng công thức/toạ độ của bản .py, để
//     bạn mở trực tiếp bằng OpenSCAD (miễn phí, https://openscad.org) trên
//     máy mình — KHÔNG cần cài gì thêm, không cần Python/pip.
//   - File .scad này **ĐÃ được chạy qua chính OpenSCAD 2025.01.19 thật**
//     (không phải mô phỏng) ngay trong sandbox, nhờ gói npm
//     openscad-wasm-prebuilt chạy qua Node.js — xem render_scad_wasm.mjs.
//     Cả 5 biến thể PART (top/bottom/pin/assembly_closed/assembly_open)
//     dựng thành khối đa diện hợp lệ ("Simple: yes", không lỗi CGAL) và
//     xuất STL thành công. Thể tích + bounding-box của top/bottom/pin khớp
//     bản .py (CadQuery/OCCT) trong sai số <0.3% (chỉ do rời rạc hoá $fn)
//     — xem cross_check.py và README §5. Đây là bằng chứng 2 lõi hình học
//     ĐỘC LẬP (OCCT vs CGAL) đồng ý với nhau, KHÔNG phải bằng chứng thiết
//     kế đã đúng công thái học/cơ học (vẫn cần in + đo thật, xem README §8).
//
// TRẠNG THÁI: `PROPOSED` — xem CLM-HW-004 / DEC-HW-006 trong
// research/claims/CLAIM_LEDGER.csv và research/context/DECISION_LOG.md.
// Kích thước đốt ngón (W_in/H_in/L) là SỐ GIẢ ĐỊNH, PHẢI đo lại bằng
// thước cặp trước khi in bản dùng thật.
//
// LỖI ĐÃ SỬA 2026-10-07 (phát hiện bởi chủ dự án khi mở file này bằng
// chính OpenSCAD trên máy mình — cảm ơn vì đã bắt lỗi!): tay đòn ngàm cài
// (latch_arm, nửa lòng tay) từng cách thành vỏ ~2.8mm, không chạm vào đâu
// -> xuất STL bị tách thành 2 mảnh RỜI, không in được nguyên khối. Đã vá
// bằng cách thêm "gốc nối" (rib) trong module latch_arm(). Kiểm chứng lại
// bằng check_connectivity.py (đếm connected components qua trimesh) — xem
// README §5a để biết chi tiết đầy đủ. BÀI HỌC: file CAD "chạy được, không
// lỗi CGAL/OCCT" KHÔNG đồng nghĩa là mọi chi tiết đều liền 1 khối in được —
// luôn chạy check_connectivity.py sau khi sửa hình học.
//
// CÁCH DÙNG:
//   1. Cài OpenSCAD: https://openscad.org/downloads.html
//   2. Mở file này. Các biến có khối "/* [Tên nhóm] */" phía trên sẽ hiện
//      thành thanh trượt trong tab Customizer (Window > Customizer).
//   3. Đổi biến PART ở cuối file để chọn xem: "top" | "bottom" | "pin" |
//      "assembly_closed" | "assembly_open"
//   4. Nhấn F5 để xem nhanh (preview), F6 để render đầy đủ CSG (bắt buộc
//      trước khi xuất STL).
//   5. File > Export > Export as STL khi PART đang là chi tiết muốn in
//      ("top" hoặc "bottom" — KHÔNG in "assembly_*", chỉ để xem).
// =====================================================================

/* [1. Kích thước đốt ngón tay — PHẢI ĐO LẠI BẰNG THƯỚC CẶP] */
L    = 24.0; // chiều dài khung dọc theo ngón (mm)
W_in = 19.0; // bề rộng trong, hướng trụ-quay (mm)
H_in = 16.0; // bề dày trong, hướng mu-lòng (mm)

/* [2. Vỏ cứng] */
t_wall = 2.2; // bề dày thành khung (mm)
// 2026-10-07 (theo yêu cầu "đổi sang hình trụ, bớt vuông cứng"): bỏ bo góc
// chữ nhật kiểu cũ (r_in/r_out). Tiết diện giờ là "viên thuốc dẹt": 2 mặt
// mu/lòng tay có 1 đoạn THẲNG rộng flat_w (chỗ dán cảm biến), 2 cạnh hông
// (bản lề + ngàm cài) bo tròn HẾT MỨC bằng 1 cung ELIP lớn. Xem capsule_prism().
flat_w = 12.0; // bề rộng đoạn thẳng ở giữa mặt mu/lòng tay (mm)

/* [3. Hốc cảm biến Velostat + đồng tự dính] */
pocket_w     = 8.0;  // bề rộng hốc
pocket_len   = 16.0; // chiều dài hốc dọc theo ngón
pocket_depth = 1.3;  // độ sâu khoét vào vách

/* [4. Rãnh luồn dây tín hiệu] */
wire_w     = 2.2;
wire_depth = 1.2;

/* [5. Bản lề - cạnh Y = -W_out/2] */
margin_x        = 2.0; // chừa 2 đầu trục X không có khớp
n_knuckle_top   = 3;   // số khớp ống thuộc nửa mu tay — PHẢI = n_knuckle_bot + 1
n_knuckle_bot   = 2;   // số khớp ống thuộc nửa lòng tay
knuckle_gap     = 0.5; // khe hở in 3D giữa các khớp ống
r_knuckle       = 3.0; // bán kính ngoài khớp ống
// 2026-10-07 (theo yêu cầu "in tại chỗ, tự do xoay ngay sau khi in" — xem
// README §5e): r_pin = bán kính LỖ trên khớp ống nửa lòng tay; khi
// PIN_INTEGRATED=true, trục đặc hàn vào nửa mu tay có bán kính =
// r_pin - pin_clearance. Trước đây khe hở là số viết tay 0.15mm, QUÁ CHẶT
// cho kiểu in-tại-chỗ (dễ dính liền 2 khối nếu máy in chưa hiệu chỉnh hoàn
// hảo) — các nguồn hướng dẫn in FDM khuyến nghị 0.2-0.4mm. Tăng lỗ lên
// 1.3mm để giữ nguyên bán kính trục đặc ~1.0mm mà đạt khe hở 0.3mm.
r_pin           = 1.3; // bán kính lỗ xỏ chốt/khớp xoay (lỗ phi ~2.6mm)
pin_clearance   = 0.3; // khe hở BÁN KÍNH trục-lỗ (mm) -- CẦN HIỆU CHỈNH
                        // theo máy in/vật liệu thật, xem README §5e
// 2026-10-08 (§5f, theo yêu cầu "đảm bảo không dễ rơi ra ngoài"): LỖI PHÁT
// HIỆN -- trục cũ (hinge_pin() dưới đây) là hình trụ bán kính KHÔNG ĐỔI
// suốt chiều dài, 2 đầu chỉ bo tròn (capsule) chứ KHÔNG có vai/mũ chặn lớn
// hơn lỗ khớp ống -> KHÔNG CÓ GÌ ngăn nửa lòng tay trượt dọc trục X và
// tuột hẳn ra khỏi trục. Khắc phục: thêm 2 "vai chặn" hình TRỤ ĐỒNG TRỤC
// (collar, bán kính pin_retain_r > r_pin) ở GIỮA khớp ống ĐẦU và CUỐI
// thuộc nửa mu tay. Mọi khớp ống nửa lòng tay (lỗ bán kính r_pin) đều nằm
// GIỮA 2 vai chặn này theo trục X nên không thể trượt dọc trục để tuột ra
// ngoài (kiểm chứng bằng check_axial_retention.py). Dùng hình TRỤ (không
// phải hình CẦU) vì hình cầu tạo điểm cực kỳ dị khi xuất STL ->
// check_connectivity.py báo nhầm "mảnh rời". Chỉ áp dụng khi
// PIN_INTEGRATED=true.
//
// ĐÍNH CHÍNH 2026-10-08 (phát hiện khi làm QA bằng ảnh render + đo thể
// tích boolean chính xác trên bản .py, theo yêu cầu "dùng vision kiểm tra
// tới khi hết lỗi"): ghi chú trước đây nói vai chặn "ẩn gọn trong boss có
// sẵn, KHÔNG tạo gờ nhô mới" -- ĐÃ KIỂM CHỨNG SAI. Boss của nửa mu tay chỉ
// là NỬA hình trụ (nửa Z>=0, xem hinge_knuckles()), còn vai chặn là hình
// trụ TRÒN ĐỦ -- nên nửa Z<0 của mỗi vai chặn lộ ra thành 1 cục u nhỏ (bán
// kính 2.2mm, dài 2mm) trong khe hở giữa các khớp ống, phía lòng tay. Đây
// là CHỦ Ý CẦN THIẾT (không phải lỗi): vai chặn phải có vật liệu ở đúng
// nửa Z<0 thì mới thực sự chặn được khớp ống lòng tay (có lỗ nằm ở Z<0).
// Đã xác nhận (trên bản .py, hình học giống hệt) cục u này KHÔNG va chạm
// khi xoay bản lề và KHÔNG vượt bán kính ngoài lớn nhất của vỏ
// (2.2mm < r_knuckle=3.0mm) -- chỉ lộ nhẹ về thẩm mỹ trong khe hở, không
// "ẩn hoàn toàn" như ghi chú cũ từng nói. Xem README §5f.
pin_retain_r    = 2.2; // bán kính vai chặn (mm) -- phải > r_pin (1.3mm) để
                        // chặn tuột. LƯU Ý: không ẩn hoàn toàn -- xem đính
                        // chính 2026-10-08 ở trên (tạo 1 cục u nhỏ lộ ra ở
                        // khe hở giữa các khớp ống, đã xác nhận an toàn).
pin_retain_len  = 2.0;  // chiều dài mỗi vai chặn (mm)
knuckle_overlap = 0.5; // phần khớp ống "ăn" vào thành vỏ để liền khối

/* [6. Ngàm cài - cạnh Y = +W_out/2] */
catch_h     = 14.0; // chiều cao khối ngàm cố định (mu tay) -- PHẢI >= (arm_h - 1.0 + 1.5)
                     // để chứa hết nấc răng gần điểm nghỉ của móc (xem latch_catch(), §5c)
catch_t     = 2.2;  // bề dày khối ngàm
tooth_h     = 0.9;  // độ nhô mỗi nấc răng
tooth_pitch = 2.6;  // khoảng cách giữa 2 nấc
arm_h       = 13.0; // chiều dài tay đòn đàn hồi (lòng tay)
arm_t       = 1.1;  // bề dày tay đòn
arm_hook    = 1.1;  // độ sâu móc ở đầu tay đòn

/* [7. Dây đai phụ - khoá an toàn lớp 2] */
strap_slot_w = 3.2;
strap_slot_h = 6.0;
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

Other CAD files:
hardware/cad/finger_shell_hinge/out/scad/assembly_open.stl
hardware/cad/finger_shell_hinge/out/assembly_open_print_in_place.stl
hardware/cad/finger_shell_hinge/out/bottom_shell_palmar_print_ready.step
hardware/cad/finger_shell_hinge/out/scad/top_shell_dorsal.stl
hardware/cad/finger_shell_hinge/out/bottom_shell_palmar.step
hardware/cad/finger_shell_hinge/out/top_shell_dorsal_print_ready.step
hardware/cad/finger_shell_hinge/out/scad/bottom_shell_palmar.stl
hardware/cad/finger_shell_hinge/out/hinge_pin.step
hardware/cad/finger_shell_hinge/out/scad/bottom_shell_palmar_print_ready.stl
hardware/cad/finger_shell_hinge/out/scad/top_shell_dorsal_print_ready.stl
hardware/cad/finger_shell_hinge/out/bottom_shell_palmar_print_ready.stl
hardware/cad/finger_shell_hinge/out/hinge_pin.stl
hardware/cad/finger_shell_hinge/out/top_shell_dorsal.step
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

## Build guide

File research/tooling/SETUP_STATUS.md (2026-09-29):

# Research tooling setup status — 2026-08-25

## Pinned source checkouts

| Tool/source | Commit | Local role | Build/runtime state |
|---|---|---|---|
| Academic Research Skills | `6837b4dfeaab` | research/reviewer/pipeline methodology | cloned; four local skill links created and verified |
| PlotNeuralNet | `e96bc852189` | Python → TikZ diagrams | cloned; PDF rendering requires a TeX runtime |
| BVLC Caffe | `9b891540183d` | legacy architecture/reference source | cloned; intentionally not built |
| PGF/TikZ | `0a859c80b47` | upstream source/reference | cloned; intentionally not installed from source |
| MiKTeX | `76d1b3bd2b69` | upstream source/reference | cloned; **not** a TeX runtime |

Authoritative full hashes and URLs: `tools/research_sources.lock.json`.

## Runtime status

- Debian 12 Bookworm detected.
- Official MiKTeX Debian path and signing-key fingerprint check are implemented in `scripts/install_miktex_debian.sh`.
- Runtime MiKTeX installation in this sandbox remains **blocked** (APT/HTTPS endpoints) — `pdflatex` not available here. This is an environment/network blocker, not evidence that the installer or MiKTeX is invalid. Install the official MiKTeX installer on the real workstation.
- The ignored `.venv` has NumPy, Matplotlib and scikit-learn (**reinstalled 2026-09-27**; + `pypdf` for local PDF text extraction — not a runtime dependency).
- Environment check result (re-run 2026-09-27): **10/11** required/target checks pass; only `pdflatex` fails. `miktexsetup` remains an optional warning.
- Third-party checkouts + 4 skill links re-verified 2026-09-27 via `bootstrap_research_tooling.sh` (all `READY`, pinned commits match lock file).

## Topic-related note (2026-08-25)

- All air-cushion/AAC artifacts (docs, cad, diagrams, simulation, pipeline, experiments, outputs, src, input baseline report, SOFA scripts) were **deleted** per DEC-TOPIC-003. No old smoke experiments remain; new experiment scripts will be added when the hardware/bench work begins.
- The five pinned third-party sources remain useful for the **new topic**: Academic Research Skills (methodology/review), PlotNeuralNet + PGF + MiKTeX (TikZ architecture diagrams), Caffe (legacy reference only).

## Commands

```bash
# Reproduce/check source trees and local ARS links
bash scripts/bootstrap_research_tooling.sh
bash scripts/bootstrap_research_tooling.sh --check

# Python core
python3 -m venv .venv
. .venv/bin/activate
python -m pip install -r requirements.txt

# Debian 12 MiKTeX runtime (requires working APT/HTTPS)
bash scripts/install_miktex_debian.sh

# Report readiness
python scripts/check_research_environment.py
python scripts/check_research_environment.py --strict
```

## Deliberate non-actions

- Do not build Caffe simply because PlotNeuralNet has Caffe-era examples.
- Do not install PGF master into a user TeX tree by default. Use the TeX distribution's PGF/TikZ package.
- Do not source-build MiKTeX unless package-manager installation is impossible on the actual workstation and the cost is explicitly accepted.

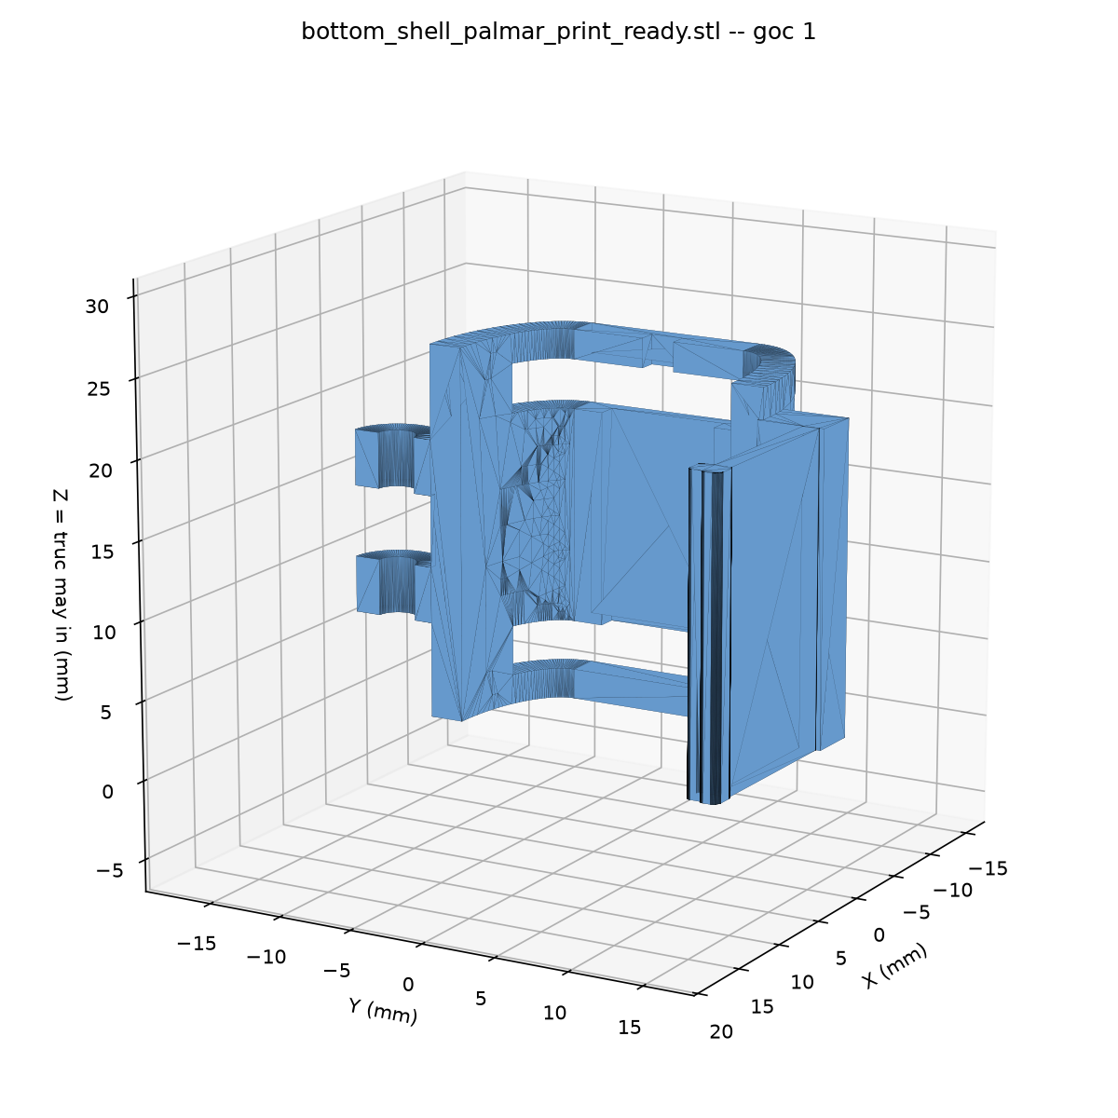
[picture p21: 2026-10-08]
hardware/cad/finger_shell_hinge/out/renders/14_bottom_print_ready_view1.png

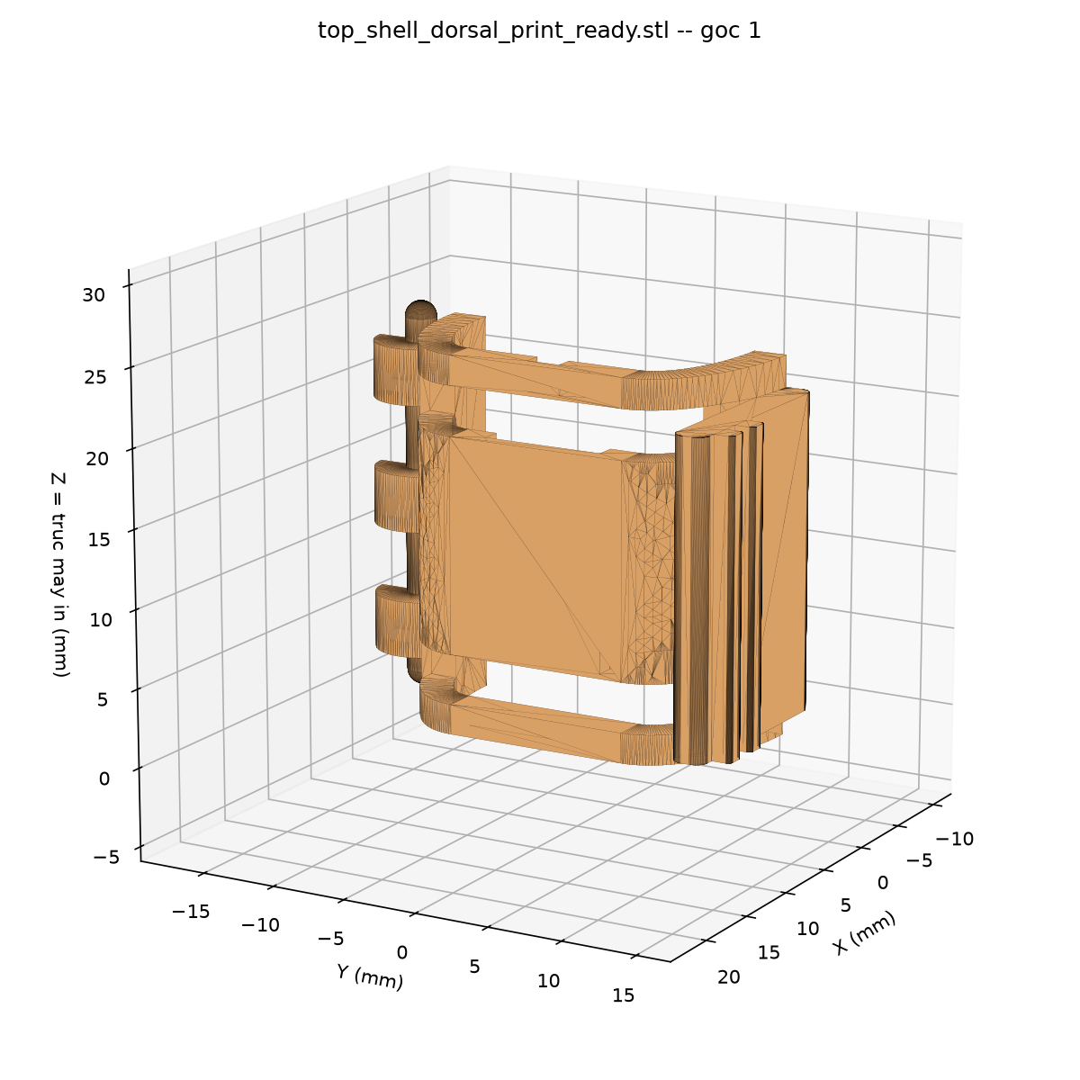
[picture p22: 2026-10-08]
hardware/cad/finger_shell_hinge/out/renders/12_top_print_ready_view1.png

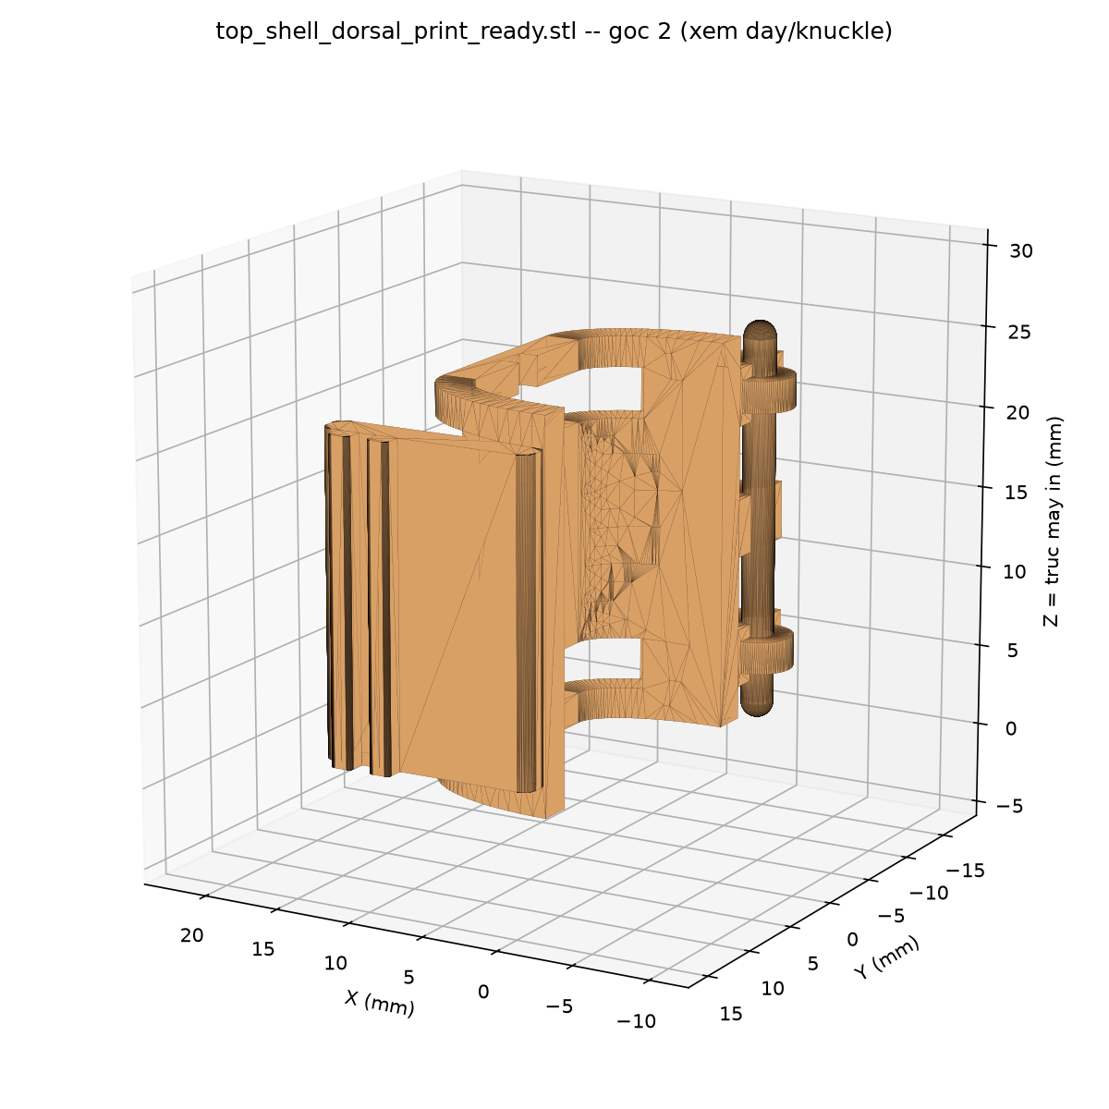
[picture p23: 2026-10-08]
hardware/cad/finger_shell_hinge/out/renders/13_top_print_ready_view2.png

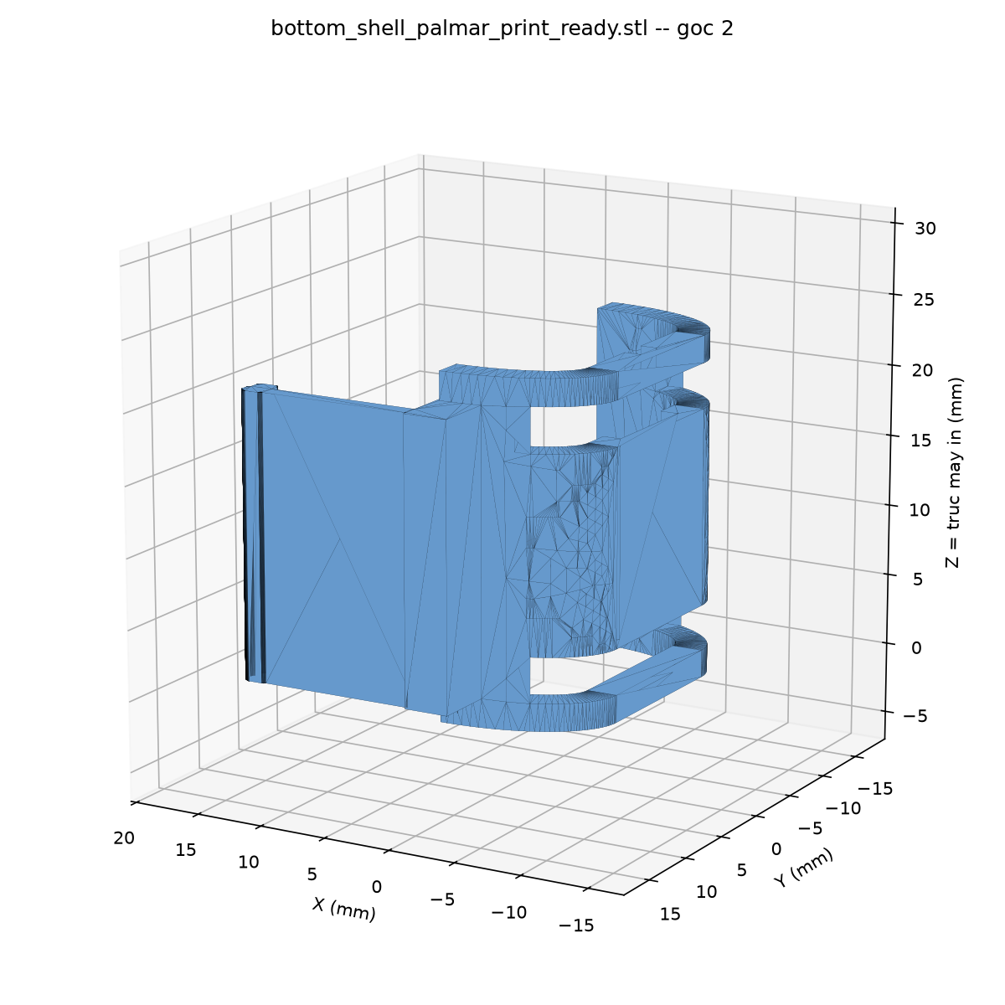
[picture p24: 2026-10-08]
hardware/cad/finger_shell_hinge/out/renders/15_bottom_print_ready_view2.png

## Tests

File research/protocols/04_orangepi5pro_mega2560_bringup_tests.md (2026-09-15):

# 04 — Orange Pi 5 Pro ↔ Arduino Mega 2560 bring-up tests (before Velostat arrives)

> ⚠️ **DI SẢN — KHÔNG ÁP DỤNG CHO ĐỀ TÀI HIỆN TẠI (2026-09-13).**
> File này được viết cho đề tài **smart insole** với **Arduino Mega 2560** — đề tài đã bị bỏ.
> Đề tài hiện tại là **găng tay theo dõi chức năng bàn tay sau đột quỵ**, dùng **ESP32-S3 + CD74HC4067** (DEC-HW-003), mức logic 3.3 V nên **không cần level shifter**.
> Giữ lại để tham khảo cách kiểm tra đường truyền/CRC/timestamp. **Không** trích như phương pháp hiện hành.
> Phương pháp hiện hành: `research/protocols/06_glove_hand_GATE_experiment.md`.

- **Purpose:** validate acquisition-to-edge transport, timing, electrical safety, ADC behavior and edge-host stability using known signals/synthetic frames. These tests are **not** sensor validation, GRF/COP validation, drift validation, or real-time performance proof until raw logs are retained and reviewed.
- **Scope:** Arduino Mega 2560 = acquisition/timestamping; Orange Pi 5 Pro = receipt, logging, diagnostics and later inference.

## 0. Electrical rule — do this before any code

### Current owner setup: direct GPIO serial

The owner reports that direct serial GPIO communication between the Orange Pi and Arduino has already been established. This protocol therefore treats direct UART as the current transport path, not a task still to be solved.

Before collecting research data, record the **actual** interface in the session manifest:

```text
Orange Pi UART device path and GPIO pins:
Mega UART pins/port:
baud rate:
level-shifter model/wiring or verified voltage-interface method:
common-ground arrangement:
logic levels measured at Mega TX and Orange Pi RX:
```

- Mega UART TX is commonly **5 V logic**; Orange Pi GPIO RX is commonly **3.3 V logic**. The log must establish how the owner protects the Pi RX path; do not infer safety from successful basic communication alone.
- Orange Pi TX (3.3 V) → Mega RX behavior also depends on the actual board/interface and must be retained in the wiring record.
- Never power motors, sensor excitation, or unknown external loads from Orange Pi GPIO. Keep grounds intentional and inspect voltage before reconnection.

USB serial remains an optional diagnostic fallback, not the primary planned transport.

## 1. Test order and records

For every test save: date/time, board revisions, USB/UART path, firmware Git commit/hash, Pi OS/kernel, baud rate, power source, command line, raw log path, result, and anomalies. Use the headers in `research/bench/templates/` where applicable.

| Test | What it falsifies | Pass evidence (not a claim before log review) |
|---|---|---|
| T0 USB enumeration | wrong cable/driver/port | Mega device appears reliably after five reconnects |
| T1 framed packet/CRC | framing or byte corruption | receiver recomputes CRC and reports sequence gaps/CRC failures |
| T2 sustained throughput | link too slow or receiver cannot keep up | measured delivered frames/s, loss, latency proxy and jitter across planned rates |
| T3 burst/reconnect | buffer overflow or fragile restart | recovery behavior and lost-frame interval recorded |
| T4 timestamp/sync | untraceable timing | Mega `micros()` plus Pi receipt time captured; offset/jitter characterized |
| T5 ADC known-input | ADC wiring/reference/noise defect | logs for 0 V, stable midscale divider, and stable high reference; inputs never float |
| T6 16-channel scan | scan-time/ADC settling problem | measured frame period, per-channel variance, cross-channel carryover test |
| T7 Pi host stress | logging breaks under CPU/disk load | repeat T2 while Pi is under documented load; compare results |
| T8 synthetic inference | pipeline interface/latency only | fixed synthetic windows reach and return through the intended process; no biomechanics claim |
| T9 power/thermal soak | resets/overheating/USB instability | voltage, temperature, reset/disconnect events and logs recorded over declared duration |

## 2. T0–T4: transport diagnostics

1. Flash `firmware/mega_link_diagnostics/mega_link_diagnostics.ino`.
2. Use USB first at 115200 baud, then 230400 and 460800 only if each lower rate is stable.
3. The firmware emits CSV-like framed lines containing a sequence number, Mega timestamp, 16 ADC slots, mode and CRC.
4. Capture raw serial output on the Orange Pi. Do not rely on terminal screenshots.
5. Run at nominal candidate frame rates (50, 100, 200 Hz) for at least 10 min each; the actual achieved rate, errors and gaps are the results.
6. Trigger a controlled reconnect during T3; record whether frame numbering restarts and how the Pi logger detects it.

### Packet fields

```text
@seq,mega_us,adc0,...,adc15,mode,crc16\n
```

- `seq` detects drops/restarts.
- `mega_us` is acquisition-side time, not wall clock.
- `crc16` protects the complete payload before the CRC field.
- ADC slots are diagnostic only until real sensor calibration.

## 3. T5–T6: ADC/scan tests without Velostat

Use a safe known voltage source or resistor divider. Do not leave analog pins floating.

1. **Ground test:** connect one channel to GND; collect baseline distribution.
2. **Midscale test:** use a stable, measured divider/reference (e.g., nominal half-scale) and record the actual voltage with a multimeter.
3. **High-reference test:** use a safely bounded known voltage compatible with the chosen ADC reference. Never exceed the Mega analog-input/reference limits.
4. **Cross-channel test:** alternate grounded and midscale channels. This reveals carryover/settling issues when scan order changes.
5. **16-channel scan:** connect each channel to a declared known state; measure actual scan/frame timing. Arduino Mega has 10-bit ADCs and 16 analog inputs, but the achieved usable rate/noise must be measured, not assumed.

Record ADC reference mode (`DEFAULT`, `INTERNAL`, or external) and never apply an external AREF voltage while firmware is configured incompatibly.

## 4. T7–T9: Orange Pi edge-host tests

- **T7:** repeat transport while writing raw logs and applying a reproducible CPU/disk stress workload. The load command and process state must be logged.
- **T8:** run a fixed synthetic feature/inference placeholder only to test process boundaries, queueing and timestamp propagation. It cannot demonstrate NPU throughput, INT8 accuracy or biomechanics.
- **T9:** operate for a declared soak duration with ordinary cooling/enclosure state. Log `uptime`, CPU temperature, storage free space, USB disconnects and application restarts. Do not report “real time” until latency distribution is measured with the actual model.

## 5. Decision criteria before Velostat integration

Advance to sensor integration only if:

1. electrical interface is documented and safe;
2. T1/T2/T3 logs permit counting CRC failures, sequence gaps, restarts and achieved rate;
3. T5/T6 show known-input behavior and expose any scan/settling limitation;
4. raw timestamp provenance survives Pi logging;
5. failures have a recorded cause or remain explicit blockers.

Velostat arrival starts a **new** phase: cell characterization, crosstalk, hysteresis, creep, calibration and reference-load tests. These transport tests do not replace that phase.

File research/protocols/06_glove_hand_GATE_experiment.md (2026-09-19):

# 06 — GATE experiment: Găng tay đánh giá & theo dõi chức năng bàn tay sau đột quỵ

> **Ngày soạn:** 2026-09-13 · **Trạng thái:** CHỜ vật liệu + phần cứng (Velostat, khung in 3D, ESP32-S3, CD74HC4067, load cell).
> **Đây là thí nghiệm quyết định đề tài sống hay chết.** Không có GATE pass ⇒ không viết kết luận.
>
> **Nguyên tắc bắt buộc:**
> - Toàn bộ GATE 0–F chạy trên **bench/phantom**, **không cần người tham gia** ⇒ không cần IRB cho các cổng này.
> - Mọi log phải lưu thô, có timestamp, có mã phiên, vào `research/bench/` (và bản gốc không bị sửa).
> - Ngưỡng PASS/FAIL phải **chốt trước khi đo** và ghi vào file này; cấm chỉnh ngưỡng sau khi thấy kết quả.

---

## 0. Bảng tổng hợp

| Cổng | Câu hỏi | Nếu FAIL |
|---|---|---|
| **GATE 0** | Sensing element tự chế có lặp lại được không? | Dừng — chưa làm được cảm biến thì không có gì để nghiên cứu |
| **GATE A** | Hệ thống có phân biệt được **hướng** tác động không? | Bỏ tính năng "cảm biến hướng"; lùi về đo lực đơn thuần |
| **GATE B** | Có tái tạo được bàn tay 3D đủ trung thực không? | Bỏ mục tiêu 3D, chỉ báo cáo chỉ số lực |
| **GATE C** ⭐ | Thay đổi chức năng thật có **lớn hơn** drift/nhiễu không? | **DỪNG ĐỀ TÀI** hoặc đổi trục nghiên cứu |
| **GATE D** | Chạy nhiều ngày có báo động giả không? | Phải tăng ngưỡng hoặc bỏ tính năng cảnh báo |
| **GATE E** | Có tự phát hiện được sensing element lỗi không? | Bỏ tính năng self-validation |
| **GATE F** | INT8 trên NPU có đủ nhanh/chính xác không? | Chạy trên CPU, ghi rõ là chưa dùng NPU |

---

## GATE 0 — Độ lặp lại của sensing element

**Câu hỏi:** Cùng một sensing element, dưới cùng một tải lặp lại, có cho cùng tín hiệu không?

**Dụng cụ:** jig nén cơ khí (in 3D/kẹp), load cell + HX711 làm tham chiếu lực, ESP32-S3 + 1 sensing element, bệ cứng.

**Quy trình:**
1. Đo `R_sensor` theo tải tăng dần rồi giảm dần (đường cong tăng/giảm) → xác định **hysteresis**.
2. Giữ tải không đổi trong ≥ 60 giây → đo **creep**.
3. Lặp chu kỳ tải ≥ 100 lần → đo **thay đổi điểm làm việc theo chu kỳ**.
4. Lặp toàn bộ ở 3 ngày khác nhau → đo biến thiên giữa các phiên.
5. Lặp với ≥ 5 sensing element khác nhau (đánh giá chế tạo có nhất quán không).

**Thước đo:** hệ số biến thiên CV (%), độ trễ chuẩn hóa, độ trôi trong 60 s, hệ số tương quan giữa hai lần đo.

**Tiêu chí PASS (chốt trước):**
- CV trong một phiên ≤ 5% ở mức tải làm việc.
- ICC giữa các phiên ≥ 0,75.
- Ghi nhận được đường cong tăng/giảm để **định lượng** hysteresis (không yêu cầu nhỏ, chỉ yêu cầu biết được).

**Nếu FAIL:** quay lại thiết kế cơ khí/electric cực trước, không chạy tiếp.

> **Bản chạy chi tiết (2026-09-19):** [`08_gate0_execution_plan.md`](08_gate0_execution_plan.md) — tách GATE 0 thành **Q1** (độ nhạy: `γ`, `ΔV/σ`) và **Q2** (mạch đọc thật có nghe thấy không: `R₀(F_p) ≤ R_max`), thêm **thí nghiệm quét trở nguồn** để đo `R_max` thay vì đi mượn 100 kΩ, thêm log trôi ≥10 ngày, và **cây quyết định khi fail**. Ngưỡng ở đó là **ĐỀ XUẤT — chủ dự án chốt trước khi đo** (`DEC-SCOPE-003` vẫn hiệu lực).

---

## GATE A — Phân biệt HƯỚNG (điểm kỹ thuật trung tâm của đề tài)

**Câu hỏi:** Với nhiều sensing element trên các vách của khung, hệ thống có xác định đúng **chiều** của lực/phản lực tác động không?

**Phantom:** khung găng in 3D gắn trên **cánh tay phantom** (hoặc bàn tay giả in 3D) có thể gây lực theo hướng biết trước bằng quả nặng/lò xo.

**Quy trình:**
1. Gây lực theo 4 hướng chuẩn trên mặt phẳng (gập, duỗi, trái, phải) ở 3 mức lực (nhỏ/vừa/lớn) × mỗi mức 20 lần.
2. Ghi đồng thời: nhãn hướng (ground truth do người đặt lực gán) + vector kênh thô.
3. Lặp ở **3 vị trí đặt lực khác nhau** trên cùng lóng ngón để kiểm tra hệ thống có phụ thuộc điểm đặt lực không.
4. Phân tích: ma trận nhầm lẫn (confusion matrix) + độ chính xác phân loại hướng.

**Thước đo:** accuracy phân loại hướng, tỷ lệ nhầm lẫn giữa cặp hướng đối diện, khoảng cách Euclid giữa vector trung bình của hai hướng đối lập.

> 📚 **Mốc tham chiếu từ y văn** (thêm 2026-09-19 sau lượt rà soát prior art; **không** đổi ngưỡng — DEC-METRIC-001): các găng đo góc khớp không-IMU đã công bố precision ~1,67% FS / RMS < 3,29° (`SRC-GRATING-GLOVE-2021`), sai số góc ±6° cho găng bend+force dùng để đánh giá chức năng tay (`SRC-FUNCASSESS-2016`), ART-Glove dùng encoder cho 22 DoF (`SRC-ARTGLOVE-2026`). **Nếu GATE A/B chỉ đạt mức "phân loại được hướng" mà sai số lớn hơn hẳn các mốc đó, phải trình bày là bước proof-of-concept và nêu rõ khoảng cách**, không so sánh một chiều với "không dùng IMU".

**Tiêu chí PASS (chốt trước):**
- Phân loại 4 hướng: accuracy ≥ **85%** trên phantom.
- Phân biệt **cặp đối lập** (gập vs duỗi): accuracy ≥ **90%**.
- Vector trung bình của hai hướng đối lập phải **ngược dấu** một cách hệ thống.

**Nếu FAIL:** loại bỏ claim "cảm biến hướng"; chuyển sang báo cáo chỉ số lực đơn hướng và ghi rõ lý do.

---

## GATE B — Tái tạo bàn tay 3D

**Câu hỏi:** Từ trường lực-hướng rời rạc, hệ thống suy luận được hướng gập/duỗi từng khớp và dựng lại bàn tay 3D ở mức chuyên gia đọc hiểu được không?

**Ground truth:** phantom có **khớp đặt được góc biết trước** (in 3D với chốt hãm ở các góc 0°, 30°, 60°, 90°) hoặc goniometer trên phantom.

**Quy trình:**
1. Đặt phantom ở từng tổ hợp góc đã biết (bắt đầu đơn khớp, sau đó đa khớp).
2. Thu dữ liệu, chạy mô hình suy luận, xuất mô hình bàn tay 3D.
3. So sánh **góc suy luận** với **góc đặt thật**.
4. Lặp lại 3 lần mỗi tổ hợp để đánh giá độ ổn định.

**Thước đo:** MAE (độ) theo khớp; RMSE; tương quan giữa góc suy luận và góc thật; đánh giá định tính của KTV (có đọc được động tác không).

**Tiêu chí PASS (chốt trước):**
- MAE ≤ **15°** cho các khớp MCP/PIP trên phantom (đây là mức của một hệ thống proof-of-concept, **không** phải mức thiết bị y tế).
- Tương quan góc suy luận vs góc thật `r ≥ 0,8`.
- KTVVLTL-PHCN xem mô hình 3D và xác nhận **phân biệt được** gập/duỗi từng ngón (đánh giá định tính, ghi lại nguyên văn).

**Nếu FAIL:** hạ mục tiêu 3D xuống "trực quan hóa mức độ kích hoạt" thay vì "tái tạo góc".

---

## GATE C ⭐ — Độ nhạy phát hiện thay đổi (TIÊU CHÍ SỐNG CÒN)

**Câu hỏi:** Thay đổi chức năng **thật** (mô phỏng) có tạo ra tín hiệu **lớn hơn** biến thiên drift/nhiễu của hệ đo trong cùng khung thời gian không?

**Thiết kế:**
1. Tạo **các mức chức năng mô phỏng** trên phantom:
   - Mức 1 — "tay khỏe": lực đầy đủ, biên độ lớn.
   - Mức 2 — "yếu vừa": chặn một phần hành trình/lực (ví dụ giới hạn biên độ ~50%).
   - Mức 3 — "yếu nặng": giới hạn ~25% + có thêm ma sát/thay đổi động học.
2. Mỗi mức đo **lặp lại** ở **nhiều ngày khác nhau** (≥ 5 phiên, ≥ 3 ngày), mỗi phiên ≥ 10 lần lặp.
3. Tính:
   - `Δ_signal` = khoảng cách giữa các mức (effect size, ví dụ Cohen's d).
   - `σ_noise` = độ lệch chuẩn **trong cùng một mức** qua các phiên (bao gồm cả drift).
4. Tính **MDC** của chỉ số: `MDC ≈ 1,96·√2·SEM`.

> 📚 **Mốc so sánh bắt buộc nêu trong báo cáo** (thêm 2026-09-19; ngưỡng PASS/FAIL **giữ nguyên**): `SRC-STEF-MDC-2026` — công cụ chuẩn STEF có ICC 0,98 và **MDC95 = 12,7 điểm** trên n=53 bán cấp; `SRC-MANUMETER-RCT-2022` — hệ đeo đã kiểm định có **MDC ≈ 31%** mức dùng tay trung bình ngày và 100–200 counting sai/giờ. Hai mốc này trả lời câu hỏi *"'MDC nhỏ' là nhỏ so với cái gì?"*: nếu MDC của chỉ số găng tay không cạnh tranh được với 31% (hoặc không giải thích được vì sao khác), GATE C được tính là FAIL về mặt *utility* dù đạt ngưỡng 2σ.

**Tiêu chí PASS (chốt trước):**
- `Δ_signal` giữa Mức 1 và Mức 3 ≥ **2 × σ_noise** (tức là tách được rõ ràng).
- Cohen's d giữa Mức 1 và Mức 2 ≥ **0,8**.
- MDC của chỉ số chính **nhỏ hơn** mức thay đổi giữa hai mức liền kề.
- **Không** có trường hợp chỉ số đảo chiều giữa các phiên ở cùng một mức.

**Nếu FAIL:** **dừng đề tài**. Phải báo cáo thẳng: *"chỉ số thu được không đủ nhạy để theo dõi tiến triển; không thể dùng cho longitudinal monitoring"*. Không được viết báo cáo như thể thành công.

---

## GATE D — Theo dõi nhiều ngày không báo động giả

**Câu hỏi:** Khi chức năng **không** thay đổi, hệ thống có im lặng không?

**Quy trình:**
1. Giữ **nguyên một mức** trên phantom, chạy ≥ 10 ngày (mỗi ngày 1 phiên, mỗi phiên ≥ 10 lần lặp).
2. Bật logic cảnh báo "có thay đổi" của hệ thống.
3. Đếm số lần hệ thống báo thay đổi **trong khi thực tế không có thay đổi**.
4. Lặp lại với điều kiện thay đổi môi trường nhẹ (nhiệt độ phòng khác nhau, tháo và đeo lại găng).

**Thước đo:** tỷ lệ báo động giả (% trên số phiên), biến thiên của chỉ số theo ngày.

**Tiêu chí PASS (chốt trước):**
- Tỷ lệ báo động giả ≤ **10%** số phiên.
- Không có **xu hướng đơn điệu giả** (chỉ số không tự trôi tăng/giảm một chiều theo ngày dù chức năng không đổi).

**Nếu FAIL:** tăng ngưỡng cảnh báo (và ghi rõ độ nhạy bị giảm), hoặc bỏ tính năng cảnh báo, chỉ báo cáo đường cong cho chuyên gia tự đọc.

---

## GATE E — Tự kiểm tra độ tin cậy (self-validation)

**Câu hỏi:** Hệ thống có phát hiện được khi **chính nó** hỏng/sai, thay vì đưa ra kết quả sai không?

**Lỗi mô phỏng có chủ đích (fault injection):**
| Lỗi | Cách tạo |
|---|---|
| Đứt dây một kênh | Ngắt một chân sensing element |
| Chập/mất tiếp xúc | Nối tắt điện cực |
| Kênh trôi mạnh | Gia nhiệt cục bộ hoặc thay đổi preload |
| Suy giảm độ nhạy | Đặt thêm lớp cản cơ khí |
| Nhiễu tăng vọt | Đưa nguồn nhiễu gần mạch đọc |

Mỗi loại lặp ≥ 20 lần.

**Thước đo:** detection rate (%), false alarm rate (%), thời gian phát hiện (số frame).

**Tiêu chí PASS (chốt trước):**
- Phát hiện ≥ **90%** các lỗi mô phỏng.
- Báo động giả trên hệ thống khỏe ≤ **5%**.
- Thời gian phát hiện ≤ **10 giây** kể từ khi lỗi xuất hiện.

---

## GATE F — Suy luận tại biên (INT8 trên NPU)

**Quy trình:**
1. Huấn luyện mô hình trên PC (baseline trước: hồi quy tuyến tính / rừng ngẫu nhiên; chỉ dùng mạng nơ-ron nếu baseline không đủ).
2. Lượng tử hóa INT8 → chuyển sang RKNN → chạy trên NPU của Orange Pi 5 Pro.
3. Đo: độ trễ trung bình/độ trễ đuôi (p95), mức tiêu thụ điện, mức giảm độ chính xác so với FP32.
4. Đo độ trễ end-to-end (từ lúc kết thúc frame trên ESP32-S3 đến lúc cập nhật mô hình 3D).

**Tiêu chí PASS (chốt trước):**
- Độ trễ suy luận ≤ **50 ms** (đủ để phản hồi gần tức thời cho người dùng).
- Mức giảm độ chính xác sau INT8 so với FP32 ≤ **2%**.
- Chạy liên tục 30 phút không treo, không rò bộ nhớ.

> Nếu NPU không dùng được: chạy trên CPU **và ghi rõ trong báo cáo là chưa triển khai NPU** — không được nói "đã triển khai INT8 trên NPU" khi chưa có log.

---

## Biểu mẫu log tối thiểu

Mỗi phiên đo phải lưu: ngày giờ, mã phiên, nhiệt độ/độ ẩm phòng, mã firmware (git hash), cấu hình kênh, giá trị R_f, số mẫu trung bình N, tốc độ khung thực đo, tải/ground truth, người thực hiện, file log thô, ghi chú bất thường.

Dùng `research/bench/templates/session_manifest.csv` và `research/bench/templates/reference_check.csv`.

---

## Câu chốt dùng khi báo cáo kết quả GATE

> "Chúng tôi không cho rằng hệ thống đo chính xác chức năng bàn tay. Chúng tôi kiểm tra xem **chỉ số thu được có đủ ổn định và đủ nhạy để theo dõi thay đổi theo thời gian hay không**, và chúng tôi công bố cả những trường hợp nó **không** làm được."

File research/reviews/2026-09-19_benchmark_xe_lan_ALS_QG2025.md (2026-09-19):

# Benchmark: báo cáo toàn văn "Xe lăn tự hành hỗ trợ bệnh ALS trong di chuyển và giao tiếp" (Cuộc thi KHKT cấp quốc gia 2024–2025, lĩnh vực HỆ THỐNG NHÚNG)

> **Nguồn:** `BCTT - QG.pdf` do chủ dự án cung cấp qua liên kết Google Drive (`drive.google.com/file/d/1H4TLHMIEwgDnas9XEzxrrRzbiZ7b4nM2`), **đã đọc 5/5 chunk = toàn văn 15 trang**, ngày 2026-09-19.
> **Dòng ledger:** `SRC-XELAN-ALS-QG2025-REPORT` (`READ_FULL`).
> **⛔ QUY tắc sử dụng (chỉ thị chủ dự án 2026-09-19):** tài liệu này là **benchmark nội bộ**. **Không** trích, **không** nêu tên, **không** dẫn số liệu của nó trong bất kỳ file nào của hồ sơ nộp (`docs/05`, `docs/bao_cao/*`, báo cáo toàn văn, poster, slide).
> **Chuẩn đánh giá ở đây = ⚑ chuẩn hội thi học sinh** (không phải chuẩn tạp chí). Mọi nhận định là **phán đoán**, không phải số đo.

---

## 1. Báo cáo đó *thực sự* dài và chặt đến đâu (đếm được, không cảm tính)

| Hạng mục | Giá trị đếm từ bản toàn văn |
|---|---|
| Độ dài | **15 trang** (A: tr. 3–4 · B: tr. 5–9 · C: tr. 10–14 · TLTK: tr. 15) |
| Cấu trúc | A. 7 mục (lý do / xác định vấn đề / mục tiêu / **tiêu chí dự án** / đối tượng & phạm vi / địa điểm / phương pháp) — B. 7 mục — C. 5 mục — TLTK |
| Hình + Bảng | **17 "Hình" + 3 "Bảng"** ≈ **1,33 mục trình bày / trang**. Phần lớn là sơ đồ khối nguyên lý + ảnh chụp thật + ảnh chụp màn hình app/đồ thị |
| Bảng vật liệu | `Bảng 1` liệt kê 6 nhóm thiết bị (Arduino Uno R3, 2× DAC MCP4725, RealSense D435i, RPLidar A1, 2× encoder 600 xung, 2× webcam) — **không có giá tiền, không có tổng chi phí** |
| Số lượng phép đo | gaze: **1000 ảnh** (dataset Kaggle, không phải dữ liệu tự thu) · sai số tọa độ: **5 điểm, mỗi điểm 1 lần** · DAC: **1 bảng 9 hướng** đo bằng đồng hồ vạn năng · PID: **bảng log 167 dòng** (input/setpoint/output) · tự hành: **0 số** (chỉ có ảnh bản đồ + ảnh app) · LLM: **310 mẫu câu** (300 train / 10 test), loss 2,6 → 0,2, **bảng so sánh 2 prompt** |
| Kiểm định thống kê | **0** (không SD, không CI, không p, không ICC, không kiểm định phân phối) |
| Cỡ mẫu người dùng | **0** — không có thử nghiệm trên bệnh nhân; ảnh "vận hành trong môi trường thực nghiệm" là nhóm tự vận hành |
| Tuyên bố đạo đức / IRB | **không có dòng nào** |
| Prior art | **2** đối thủ nêu trong văn bản ("Xe lăn điều khiển bằng mắt" giải nhì ISEF 2016; WHILL) — **không có bảng differentiate**, không có mức-đã-đọc |
| Tài liệu tham khảo | **9** mục; phần lớn là **blog / Wikipedia / trang hãng / trang ROS wiki / trang Kaggle**; **0 DOI**, **0 bài báo phản biện** |
| Tiêu chí PASS | nêu dạng số ("sai số dưới 2 cm", "8 hướng", "2 ngôn ngữ", "3 câu văn") nhưng **không có quy trình chốt trước khi đo**, không có cổng nào bị fail được báo cáo |
| Giới hạn | §C.5 "Hướng phát triển" = **1 đoạn**, nội dung: "các module điện tử đều đang sử dụng sẵn có trên thị trường, chưa chủ động thiết kế nên một số thông số chưa tối ưu" |
| Kết quả | giải **Nhất** Cuộc thi KHKT cấp quốc gia 2025 (19–21/3/2025, TP.HCM), lĩnh vực **Hệ thống nhúng**; sau đó **giải Tư ISEF 2025**, ISEF xếp vào **Robotics and Intelligent Machines** (theo báo chí + trang isef.net, đã verify ở lượt trước) |

### 1.1 Cái họ **bắt buộc phải có** để thắng (theo quan sát)
1. Một **vật thật chạy được** + ảnh chụp nó đang chạy (Hình 12–17).
2. **Vài con số** tự đo, mỗi mục tiêu 1 con số, đặt cạnh mục tiêu (2 cm, 99,2 %, 1 m/s, loss 0,2).
3. Sơ đồ nguyên lý cho **từng** module (Hình 1–7) — người đọc không cần chạy được cũng hiểu hệ thống ghép kiểu gì.
4. Một chuỗi "lần đầu tiên / chưa ai làm đồng thời" **cụ thể** (chưa tích hợp theo dõi đồng tử **vào** xe lăn tự hành + chưa dùng NLP cho giao tiếp) — không cần bảo vệ bằng tra cứu.
5. Chi phí tự chế / phần cứng dùng sẵn nêu bằng **tên linh kiện**, không cần giá.

### 1.2 Cái họ **không cần** mà vẫn thắng (thông tin đắt giá nhất cho ta)
Bảng prior art · mức-đã-đọc của nguồn · kiểm định thống kê · protocol chốt trước khi đo · cỡ mẫu người dùng · tuyên bố IRB · danh sách "anti-claims" · log công khai · báo cáo kết quả fail. **Tám thứ này đều là thứ đề tài ta đã có hoặc đã lên kế hoạch có.**

---

## 2. Ba điểm mà nếu chỉ đọc báo cáo cấp quốc gia thì **không** thấy (đối chiếu ISEF abstract)

| Đại lượng | Bản QG (15 tr.) | Bản ISEF (abstract) | Bài học cho ta |
|---|---|---|---|
| Độ chính xác gaze | "99,2 %" = **992/1000 ảnh** đúng *hình dạng + tâm đồng tử* | "97,11 %" accuracy of **gaze point** | cùng một chữ "accuracy" cho hai construct khác nhau. Ta đã có quy tắc cấm loại lẫn lộn này (`AGENTS.md`: không ADC→N/độ) → **giữ và nêu thẳng trong báo cáo** |
| Chất lượng điều hướng | **không có số** (chỉ ảnh bản đồ + ảnh app) | **0,12 m** sai lệch bám quỹ đạo, **93,33 %** phiên tự hành đến đích | vòng sau **đòi số ở cấp hệ thống**, không chấp nhận "chạy được". → chính là GATE B + GATE D của ta |
| Giao tiếp | "3 câu văn, 2 ngôn ngữ, Telegram" (định tính) | "**< 5,33 s**/câu" | độ trễ là con số rẻ nhất để thêm → `fps_meas` + độ trễ đầu–cuối đã nằm trong `protocols/08` G0.9 |

**Suy luận (phán đoán, ⚑):** họ phải *chèn thêm* 4 chỉ số định lượng để đi thi quốc tế. Nghĩa là ban tổ chức/quốc tế chấm bằng **số đo hệ thống**, không bằng sơ đồ. Đề tài ta nên **làm luôn từ vòng quốc gia** phần mà họ phải làm ở vòng quốc tế — đó là chỗ rẻ nhất để vượt.

---

## 3. Đối chiếu trực tiếp: cùng một "ô" trong báo cáo, ai hơn ai

| Ô trong báo cáo (form quốc gia) | Họ (QG 2025) | Ta **hôm nay** | Ta **sau GATE 0 + GATE C** | Phán đoán ⚑ |
|---|---|---|---|---|
| Vật thật | Xe lăn + 6 module, chạy được, có ảnh | **0** — jig chưa chế tạo | phần tử áp trở + 1 ngón trên jig + ảnh log | **họ hơn hẳn** cho tới khi ta có ảnh thứ nhất |
| Con số cho từng mục tiêu | 5 số | **0** | 6 con số tự đo (review `…_scope_options.md` §12) | ngang, rồi hơn |
| Cơ sở của con số | 1 lần đo/điểm | protocol + ngưỡng **chốt trước** | CV, ICC, MDC, ENOB, `fps_meas` | **ta hơn rõ** |
| "Độ tin cậy của dữ liệu" | không đề cập | cờ `UNRELIABLE` + GATE E (bơm lỗi) | phát hiện lỗi ≥ 90 %, báo động giả ≤ 5 % | **ta hơn** (và giải thích được bằng 1 ảnh: đồ thị có 2 đường, một đường bị đánh dấu loại) |
| Theo dõi theo thời gian | không có | — | ≥ 10 ngày drift-only + đường cong theo tuần | **ta hơn đúng chỗ họ trống** |
| Vấn đề người dùng / tính cấp thiết | số ALS của Mỹ (1 trang mạng) | dịch tễ VN: 1.541/100.000 *(verify)* + 80 % *(verify)* | + **10 phiếu phỏng vấn KTV** (chị tác giả làm nghề) | **ta hơn về độ địa phương**, nếu lấy được phỏng vấn |
| An toàn | chọn 1 m/s "để đảm bảo an toàn" | rig chỉ tác động phantom; **cấm** thử trên người; `CLM-SAFE-001` | + bộ 3 chân (moment/vòng dòng/giới hạn thời gian) | ngang ở câu chữ, **ta hơn ở bằng chứng** (log dòng thô 2026-09-05) |
| Giới hạn | 1 đoạn mơ hồ | Phụ lục A `docs/05` (liệt kê cái **không** nói) | + cổng nào fail thì nói fail | **ta hơn**, nhưng phải *trình bày ngắn* — họ chỉ dành 3 dòng |
| Đạo đức/IRB | không có dòng nào | 5 điều + quy trình | — | **ta hơn, và không mất gì**; nhưng đừng biến thành 2 trang (hội đồng không quen đọc) |

---

## 4. Đánh giá lại đề tài của bạn sau khi đọc benchmark (thay đổi so với `2026-09-19_project_ceiling.md`)

### 4.1 Trần ⚑: **nâng một bậc có điều kiện** — và có một quyết định chiến thuật mới
- **Cao hơn:** chuẩn thực tế của hội đồng **không phải** "độ chặt khoa học" (họ cho một báo cáo 15 trang, **0 kiểm định thống kê, 0 prior art table, 0 IRB, 0 số đo điều hướng** đạt giải Nhất quốc gia + giải Tư ISEF). Mọi thứ ta đã làm (134 nguồn có mức đọc, 7 cổng, ngưỡng chốt trước, anti-claims) **nằm trên** mặt bằng đó, không phải "quá mức cần thiết". ⇒ **giữ toàn bộ**, nhưng **đừng để nó phình thành 40 trang**.
- **Điều kiện:** toàn bộ lợi thế trên là **hứa hẹn**. Lợi thế của họ là **đã có**. Ở vòng chấm, 1 ảnh chụp thiết bị đang chạy + 1 bảng số thắng 5 trang phương pháp luận.
- **Quyết định chiến thuật mới — chọn lĩnh vực:** họ thắng ở **HỆ THỐNG NHÚNG** với một thiết bị y tế-trợ năng, và **ISEF lại xếp** cùng dự án đó vào Robotics. ⇒ đề xuất cho ta (chủ dự án quyết): **chính = Hệ thống nhúng (Embedded Systems)**, **phụ = Y sinh – Khoa học sức khỏe**. Lý do: bằng chứng của ta là *độ lặp, nhiễu, độ trễ, cổng pass/fail* — đúng ngôn ngữ của giám khảo kỹ thuật; đưa vào ô Y sinh sẽ mời câu hỏi "bệnh nhân đâu?" mà ta **không có quyền** trả lời trước IRB.

### 4.2 Ngân sách hình thức phải bắt chước (đây là chuẩn thắng, không phải chuẩn ta tự đặt)
| Chỉ tiêu hình thức | Ngưỡng nên tự đặt cho ta |
|---|---|
| Độ dài báo cáo toàn văn | **15–20 trang** (không phải 40). `docs/02` 387 dòng là **tài liệu nội bộ**, nén xuống còn **~2 trang** trong hồ sơ |
| Mật độ mục trình bày | **≥ 1,3 hình/bảng trên trang** → 15 trang ⇒ **≥ 20 ô**; mỗi GATE **được dành trước 1 ô** (ảnh + bảng số) |
| Ảnh bắt buộc | phần tử cảm biến trên tay; jig + tải treo; oscilloscope/log; dashboard; **1 ảnh "thử nghiệm"** (trên **phantom**, chú thích rõ "chưa thử trên người") |
| TLTK | 12–15 mục, **có DOI cho ≥ 8** — chỉ cần dùng danh sách must-cite `docs/02` §10 + ledger. Đây là chỗ rẻ nhất để **hơn hẳn** benchmark (họ: 0 DOI, 9 link blog) |

### 4.3 Bốn việc nên làm, theo thứ tự tác dụng
1. **Chạy `protocols/08` GATE 0** (blocker duy nhất: bạn điền 9 ô "Chốt?" ở §7) → đổi "hứa hẹn" thành "đã có", và có **ảnh + bảng số đầu tiên**.
2. **Bỏ hết ảnh chỉ để minh hoạ** khỏi hồ sơ nộp; mỗi sơ đồ phải kèm 1 số đo hoặc 1 kết luận pass/fail.
3. **Sửa `docs/05` §1**: chốt lĩnh vực (đã gắn khuyến nghị ở trên) — việc này ảnh hưởng tới *cả danh sách đối thủ bị chấm cùng*.
4. **Chỉ báo cáo phần đã đo** theo đúng kiểu họ làm: 1 mục tiêu = 1 con số = 1 ô trình bày; phần ta *hơn* (MDC/ICC/UNRELIABLE) đặt ở **Bảng C.4** (bảng đối chiếu tiêu chí A.3 ↔ số đo), không đặt ở phần lý thuyết.

### 4.4 Năm thứ **không** nên bắt chước (để ta không tự hạ mình xuống benchmark)
1. Đo **1 lần** cho mỗi điều kiện rồi tuyên bố "đạt" (bảng 5 điểm gaze của họ) — của ta mỗi điểm ≥ 3 lần, nêu CV.
2. Trộn construct trong một chữ "accuracy" (99,2 % mức ảnh ≠ 97,11 % mức tọa độ).
3. Paste nguyên bảng log 167 dòng vào báo cáo mà **không** rút thành 1 thước đo (hình 11 của họ) — của ta: log thô để trong repo, báo cáo chỉ lấy thống kê + 1 đồ thị.
4. Đánh giá mô hình học bằng **2 ví dụ minh hoạ** (bảng 3 của họ) — nếu ta lượng tử hoá INT8 thì phải nêu **độ chính xác trên tập kiểm tra + độ trễ**, không kể chuyện "câu trả lời hay hơn".
5. TLTK toàn blog/Wikipedia. Không bắt buộc phải trích tạp chí ở vòng quốc gia, nhưng **nó rẻ** và không có lỗi gì khi làm.

---

## 5. Kết luận một câu

**Đọc xong benchmark, vị thế của đề tài bạn tốt hơn tôi đoán: về phương pháp, bạn đang ở trên mức của một báo cáo đã đoạt giải Nhất quốc gia + giải Tư ISEF; về vật thật và con số, bạn đang ở 0.** Toàn bộ khoảng cách còn lại nằm ở đúng một chỗ — `GATE 0` chưa chạy vì chưa có 9 ngưỡng được chốt — và đó là việc của chủ dự án, không phải việc của tôi.

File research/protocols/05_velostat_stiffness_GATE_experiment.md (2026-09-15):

# GATE experiment — Hướng C: Velostat dynamic-pressure có đo được độ cứng mô không?

> ⚠️ **SUPERSEDED — KHÔNG DÙNG (2026-09-13).**
> File này là GATE experiment của Hướng C (**theo dõi độ cứng mô gan chân / sàng lọc DFU**), đã bị bỏ ngày 2026-08-28 vì GATE 3 (Usefulness) yếu.
> GATE experiment hiện hành: `research/protocols/06_glove_hand_GATE_experiment.md`.

**Ngày soạn:** 2026-08-26 · **Trạng thái:** CHỜ vật liệu (Velostat). Đây là thí nghiệm **quyết định** Hướng C sống hay chết.

## Câu hỏi gate (duy nhất)
> Một cảm biến/mảng Velostat giá rẻ, dùng **đáp ứng ĐỘNG** (nén lặp, tải ngắn), có **phân biệt được các mức độ cứng mô khác nhau** (mô phỏng: mô khỏe → callus → mô xơ tiểu đường) **VƯỢT LÊN TRÊN độ trôi/trễ của chính nó** không?

Nếu KHÔNG → Hướng C sụp về vật lý → bỏ hoặc đổi trục.

## Giả thuyết nền (đã có bằng chứng y văn)
- Độ cứng mô gan chân **tăng** ở bàn chân tiểu đường/callus và **là biomarker nguy cơ loét** (đã thiết lập — không cần chứng minh lại).
- Vật liệu cứng hơn → **biến dạng ít hơn ở cùng lực**, và **đáp ứng động (tốc độ hồi, diện tích vòng trễ chuẩn hóa) khác** → Velostat đọc được.

## Dụng cụ (rẻ, bench, không cần người/IRB)
1. **Phantom độ cứng biết trước** (ground truth): silicone/polyurethane nhiều mức Shore (mềm ~ mô khỏe; trung bình ~ callus; cứng ~ mô xơ). Hoặc hydrogel điều chỉnh cross-linking (như bạn đề xuất).
2. **1 mảng Velostat** (hoặc 1–2 ô) + điện cực + **Arduino Mega** đọc ADC.
3. **Jig nén** cố định: 1 đầu ấn phẳng gắn vào trục (in 3D / kẹp), nén vuông góc, độ sâu/lực lặp lại.
4. **Cảm biến lực tham chiếu** (load cell rẻ + HX711) để biết lực thật đặt vào (làm chuẩn, KHÔNG phải force plate).
5. **Bệ cứng** đặt phantom (để lực truyền qua phantom, không qua nền mềm).

## Quy trình
**A. Đo đáp ứng động theo độ cứng (core):**
- Đặt phantom lên bệ cứng → Velostat ở trên → jig nén **lặp** (vd 20 chu kỳ, cùng biên độ lực, cùng tốc độ), ghi tín hiệu Velostat + load cell.
- Lặp với **từng mức Shore** (mỗi mức ≥3 mẫu, ≥3 vị trí để giảm nhiễu).

**B. Tách tín hiệu mô khỏi drift của cảm biến (self-validation):**
- **Ô tham chiếu / đo trên bệ cứng:** nhấn Velostat lên **bề mặt cứng đã biết** (không có phantom) → đây là **drift thuần của cảm biến** theo thời gian/chu kỳ.
- Trừ phần drift này khỏi tín hiệu đo trên phantom → phần còn lại = **đáp ứng của phantom (mô)**.

**C. Ổn định dài ngày (mô phỏng longitudinal):**
- Đo lại **cùng 1 phantom** mỗi ngày trong 5–7 ngày → kiểm tra hệ **không báo động giả** khi độ cứng không đổi (dù cảm biến trôi).

## Feature cần trích (chống drift — theo đúng ý bạn)
- **Tỷ lệ slope**: slope nhánh nén / slope nhánh nhả.
- **Vòng trễ chuẩn hóa**: diện tích vòng trễ / (đỉnh lực × đỉnh chuyển vị).
- **Độ cứng động proxy**: Δlực/Δbiến dạng ở pha nén (sau khi trừ drift).
- **Đạo hàm theo ngày**: tốc độ đổi của các metric trên (cho phần longitudinal).

## Tiêu chí PASS / FAIL (định lượng, quyết định)
- **PASS-A (phân biệt):** 3 mức Shore tách biệt rõ — vd effect size lớn / phân loại 3 lớp accuracy cao / chồng lấn phân bố thấp.
- **PASS-B (tương quan):** metric (đã trừ drift) **tương quan đơn điệu** với Shore đã biết (R² khá, vd ≥0.7).
- **PASS-C (tín hiệu > drift) — QUAN TRỌNG NHẤT:** biên độ tín hiệu do **đổi độ cứng** phải **lớn hơn** biên độ drift của cảm biến trong cùng khung thời gian (vd tỷ lệ ≥2:1). **Nếu FAIL-C → Hướng C chết.**
- **PASS-D (longitudinal):** đo lại cùng phantom nhiều ngày → không có "cảnh báo giả" vượt ngưỡng.

## Đọc kết quả
- **PASS hết** → Hướng C khả thi → viết proposal đầy đủ; novelty neo vào **(1) dynamic-pressure stiffness proxy** (vật lý), các phần (2)(3) là execution/hỗ trợ, KHÔNG claim là mới.
- **FAIL-C** (drift lấn át) → Hướng C sụp → báo thẳng, đổi trục (bỏ Velostat hoặc bỏ ràng buộc human-pressure).
- **FAIL-A/B nhưng PASS-C** → tín hiệu có nhưng yếu/ồn → cân nhắc cải thiện jig/feature hoặc hạ tham vọng.

## Ghi chú trung thực
- Gate này **không** chứng minh giá trị lâm sàng (cần bệnh nhân + theo dõi dài, ngoài phạm vi học sinh). Nó chỉ chứng minh **tính khả thi vật lý** của cảm biến — đủ để làm đề tài proof-of-concept bench cho ViSEF/ISEF.
- Không claim chẩn đoán; chỉ "sàng lọc/theo dõi nguy cơ".

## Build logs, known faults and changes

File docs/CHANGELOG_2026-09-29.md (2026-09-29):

# BẢN CẬP NHẬT ĐẦY ĐỦ THEO Ý OWNER — 2026-09-29

> **Phạm vi:** mọi thay đổi / bổ sung / loại bỏ do owner nhắn từ khi gửi bản Drive (báo cáo mới nhất) tới nay.
> **Ký hiệu trạng thái:** [repo ✅] = đã vào repo · [Drive ⏳] = chờ bạn sửa trên bản Word ·
> [bạn ⏳] = chờ bạn làm/mua/gửi số · [giữ] = quyết định giữ nguyên.
> Tham chiếu: checklist M-01..M-27 (`research/notebook/2026-09-29_measurability_M-checklist.md`),
> outline v3.0 (`docs/OUTLINE_BAOCAO_VISEFD.md`).

---

## I. 🔄 THAY ĐỔI (15 mục)

| # | Nội dung bạn chốt | Trạng thái |
|---|---|---|
| T-01 | Tần số quét: 50 Hz → **20 Hz danh định** (M-02) | [repo ✅] outline v3.0 A.3/C.3 · [Drive ⏳] sửa §8.1/Hình 7 |
| T-02 | Định nghĩa kênh: "12 kênh vi sai" → **kênh = phần tử đơn; 12 + 1 chuẩn = 13 đầu vào; 6 cặp vi sai** (M-04) | [repo ✅] B.1/B.4 · [Drive ⏳] sửa §5.2/§7.1 |
| T-03 | "INA128 / INA333" → **INA333 duy nhất** (M-16) | [repo ✅] B.1/B.3 · [Drive ⏳] sửa Hình 9/10 |
| T-04 | Vex/G/S: số cũ chưa công nhận → **đo R(F) thật rồi tính lại toàn chuỗi** (M-01/M-17) | [bạn ⏳] đo DMM + quả cân |
| T-05 | Số §8.2 "qua thực nghiệm" → **dán "minh họa" hoặc ghi xuất xứ máy/người/ngày/N/log** (M-06/M-07) | [Drive ⏳] §8.2 + caption Hình 4/5/13 |
| T-06 | Hằng số AAN (1,2 s / 5 N / EI_th) → **"giá trị đặt trước, chờ kiểm định trên giàn"** (M-09) | [Drive ⏳] §10.2 |
| T-07 | M6 "phổ V_base" → **bản thu nhỏ: cửa sổ V_base + 20–30 lần tháo/đeo, giữ target 80%** | [repo ✅] A.3/C.2 · [Drive ⏳] §5.2-M6/§11.2 |
| T-08 | AI "xử lý dữ liệu" → **dự đoán + cảnh báo, thà báo nhầm còn hơn bỏ sót (recall-oriented), KTV duyệt** → chốt cuối: **luật thường gánh chính + 1 thực nghiệm đối chứng rules-vs-ML** (không phải AI trang trí) | [repo ✅] B.5/C.5 · [Drive ⏳] sửa §9.1/Hình 7/10 |
| T-09 | Nhiệt độ: **giữ nhưng thu hẹp** — log T/RH mọi phiên + 1 đồ thị trôi-vs-T + hệ số r từ dữ liệu C1.8, không chương riêng | [repo ✅] B.4 · [Drive ⏳] sửa §8.3/Hình 6 |
| T-10 | M6: ~~bỏ~~ → **RÚT LẠI, GIỮ** (quyết định bỏ đã hủy) | [repo ✅] giữ 2 vòng lặp · bản Drive giữ nguyên M6 |
| T-11 | Ngân sách: "<1,5M cả hệ thống" → **tách "thiết bị đeo <1,5M" vs "trạm dùng chung"** (M-21) | [repo ✅] B.8 · [Drive ⏳] sửa §5.1/Tóm tắt |
| T-12 | Dẫn động giàn: cáp Bowden → **khớp cứng (rig/phantom only)**; **1 servo/ngón, MCP+PIP liên động**; kiểm định xong 1 ngón trước | [repo ✅] B.3 · [bạn ⏳] ngân sách mô-men + test nhiệt (M-19) |
| T-13 | DMM chính = **FNIRSI 2C23T theo datasheet** (10k count, 0,5%); DMM rời = máy phụ, **không tra model** (DEC-INST-001) | [repo ✅] sổ tay L1–L6/PB-2 |
| T-14 | Orange Pi 5 Pro = **trạm dùng chung (trường đã có, 0 đồng)**; đã test INT8 + xử lý ảnh OK (chờ 5 số để viết claim — M-08) | [repo ✅] B.1/B.3 · [bạn ⏳] gửi model/input/latency/RKNN/log |
| T-15 | E2E vận hành theo **trần <10M, chỉ ghi sổ tay, không vào báo cáo** (DEC-BUDGET-002) | [repo ✅] notebook §5 (~5,5M) |

---

## II. ➕ BỔ SUNG (12 mục)

| # | Nội dung bạn chốt | Trạng thái |
|---|---|---|
| B-01 | **Phân loại sự kiện E1–E4** (spike/rung/tuột/bão hòa, định nghĩa ở mức tín hiệu) + **timeline sự kiện + báo cáo tuần PDF** + vòng lặp **KTV ngồi nhà duyệt** (AI gắn cờ, người diễn giải — không nói "AI phát hiện co giật") | [repo ✅] B.5/B.7/C.5 · [Drive ⏳] thêm vào §9/§11 |
| B-02 | **Camera đối chứng góc** (ArUco, P1) + **thước đo góc chuẩn chính** (P0) cho GAP (M-13) | [repo ✅] B.6 · [bạn ⏳] mua thước (~50k) |
| B-03 | **Thực nghiệm đối chứng rules-vs-ML** duy nhất (P1): baseline luật ngưỡng → ML chỉ giữ nếu thắng có bằng chứng | [repo ✅] B.5/C.5 |
| B-04 | **Công thức EI tường minh** (công thức + cửa sổ + chuẩn hóa + ngưỡng) viết trước khi thu dữ liệu (M-25) | [bạn ⏳] viết |
| B-05 | **Người đeo + an toàn**: ghi rõ ai đeo (kể cả thành viên nhóm), khi nào, biện pháp an toàn (M-26) | [bạn ⏳] viết → [Drive ⏳] §7.2 |
| B-06 | **Đồ nghề chốt + phương pháp**: C1.1 tách 3 chân (ADS1115 log + scope chứng kiến + shorted-input); chuẩn tĩnh = quả cân; load cell chỉ động + đối chứng | [repo ✅] A.6/notebook §2 |
| B-07 | **3 bẫy thao tác 2C23T**: DMM manual < 0,7 V · gen 100 Ω + dùng square/DC · BNC nhẹ tay | [repo ✅] notebook L2/PB-2 |
| B-08 | **Shopping P0**: HX711 (đầu tiên) · ADS1115/INA333 chính hãng · SHT30 · cân túi/quả cân · thước đo góc · ẩm-nhiệt kế · lò xo · vít · PETG | [bạn ⏳] mua |
| B-09 | **BOM E2E ~5,5M** (găng ~1,2M + giàn-đo ~3,2M + dự phòng ~1M) — sổ tay only | [repo ✅] notebook §5 |
| B-10 | **B.9 bảy nhóm câu cấm** + ma trận kiểm định C + outline v3.0 + A1/A2/A3/A4/A6 viết lại | [repo ✅] |
| B-11 | Điều kiện bỏ phanh: **nghiệm thu vít me tự hãm + 1 khóa cổ thủ công** (M-20) | [bạn ⏳] nghiệm thu |
| B-12 | Sửa cite: 1,5M "ước tính của nhóm" (M-22) · 80% → Cochrane/Langhorne, 85% tìm nguồn hoặc cắt (M-23) · *Engineering* 2024, *Device* 2024, gỡ cite không DOI (M-24) | [repo ✅] A.1 + refs · [Drive ⏳] Tóm tắt/§3/TLTK |

---

## III. ➖ LOẠI BỎ (14 mục)

| # | Nội dung bạn chốt bỏ | Trạng thái |
|---|---|---|
| R-01 | Claim **"suy luận INT8 < 15 ms"** (chưa đo — chỉ quay lại bằng benchmark thật) (M-08) | [repo ✅] B.5 · [Drive ⏳] xóa §9.1/Hình 7 |
| R-02 | **Phân loại MAS / chẩn đoán / AI-clinical** — từ chối Nâng cấp 1 (M-15) | [không vào báo cáo] |
| R-03 | **AAN trên người / vòng kín lực lên người** — từ chối Nâng cấp 2; AAN chỉ trên phantom (M-12/M-15) | [repo ✅] A.4/B.3 · [Drive ⏳] viết lại §10 |
| R-04 | Chữ **"triệt tiêu hoàn toàn / triệt để"** → "giảm + định lượng phần dư" (M-10) | [repo ✅] B.9 · [Drive ⏳] §8.3/§12.1 |
| R-05 | **Góc "quy đổi từ tín hiệu"** ADC→độ (M-13) | [Drive ⏳] sửa Hình 4 |
| R-06 | **Suy nguyên nhân GAP** ("do yếu cơ/co cứng") (M-14) | [Drive ⏳] sửa §8.2 |
| R-07 | **"RAL giảm = bệnh cải thiện"** → "đặc trưng giao thức kiểm định" (M-11) | [Drive ⏳] sửa §10.3 |
| R-08 | Ngôn ngữ AAN trên người ("tay người bệnh", "bảo vệ khớp") (M-12) | [Drive ⏳] sửa §10.2/Hình 12 |
| R-09 | **200 Hz đa kênh** + 50 Hz danh định (M-02/M-03) | [repo ✅] · [Drive ⏳] |
| R-10 | **ML suy luận gập/duỗi trên NPU** — dấu vi sai đã làm việc đó | [repo ✅] B.5 · [Drive ⏳] sửa Hình 10 |
| R-11 | Mục tiêu **3D/EKF/IMU-từng-đốt** khỏi giai đoạn này → hướng phát triển | [repo ✅] B.6/C.8 · bản Drive §12.2 giữ nguyên |
| R-12 | **Chương "ảnh hưởng nhiệt độ" riêng** (đã thu hẹp ở T-09) | [Drive ⏳] |
| R-13 | **[17] dạng "khảo sát bệnh viện"** → tham khảo ẩn danh trên giấy (M-24) | [repo ✅] A.5 · [Drive ⏳] sửa TLTK [17] |
| R-14 | §12 **"chế tạo thành công… đạt trọn vẹn"** (0 số liệu) → hạ về đúng mức (M-05) | [Drive ⏳] viết lại §12.1 |

**Đã bỏ khỏi danh sách mua:** DMM spare (~500k) — 2 DMM hiện tại đủ · Tra model DMM rời — không làm.

---

## IV. VIỆC CỦA BẠN (gom từ các ⏳ — 8 việc)

1. Đo R(F) thật (DMM + quả cân) → trả lời M-01/M-17 (Vex, G, S, SNR).
2. Viết công thức EI (M-25) + chốt 9 ngưỡng `protocols/08` §7 trước khi đo.
3. Viết mục người đeo + an toàn (M-26).
4. Gửi 5 số INT8 (model/input/latency/RKNN/log) (M-08).
5. Shopping P0 (B-08) — HX711 trước tiên.
6. Ngân sách mô-men + test nhiệt servo (M-19) · nghiệm thu vít me + khóa cổ (M-20).
7. Sửa bản Drive theo các mục [Drive ⏳] (15 chỗ).
8. Xác nhận Pi bản RAM mấy GB + nguồn/thẻ (cho đủ hồ sơ).

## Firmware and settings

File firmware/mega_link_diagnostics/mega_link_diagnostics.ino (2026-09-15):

// ============================================================================
// ⚠️  DI SẢN — KHÔNG ÁP DỤNG CHO ĐỀ TÀI HIỆN TẠI (2026-09-13)
// Sketch này viết cho Arduino Mega 2560 trong đề tài smart insole (đã bỏ).
// Đề tài hiện tại dùng ESP32-S3 + CD74HC4067 (DEC-HW-003).
// Giữ lại chỉ để tham khảo khung đóng gói frame/CRC. Không dùng trong báo cáo.
// ============================================================================

/* Diagnostic transport firmware only — no GRF/COP/calibration claim.
   USB serial is the recommended first link to Orange Pi. */
#include <Arduino.h>

const uint8_t CHANNELS = 16;
const uint32_t BAUD = 115200;
const uint16_t FRAME_HZ = 100; // measured actual rate is the result
const uint32_t PERIOD_US = 1000000UL / FRAME_HZ;
uint32_t seqNo = 0;
uint32_t dueUs = 0;

uint16_t crc16_ccitt(const char *data) {
  uint16_t crc = 0xFFFF;
  while (*data) {
    crc ^= (uint8_t)*data++ << 8;
    for (uint8_t i = 0; i < 8; i++) crc = (crc & 0x8000) ? (crc << 1) ^ 0x1021 : crc << 1;
  }
  return crc;
}

void setup() {
  Serial.begin(BAUD);
  dueUs = micros();
  Serial.println(F("# mega_link_diagnostics v1; ADC values are uncalibrated diagnostics"));
}

void loop() {
  uint32_t now = micros();
  if ((int32_t)(now - dueUs) < 0) return;
  dueUs += PERIOD_US;
  // Do not catch up with an unbounded loop: record schedule misses through timestamps.
  uint16_t a[CHANNELS];
  for (uint8_t i = 0; i < CHANNELS; i++) a[i] = analogRead(i);
  char payload[220];
  int n = snprintf(payload, sizeof(payload), "@%lu,%lu", (unsigned long)seqNo++, (unsigned long)now);
  for (uint8_t i = 0; i < CHANNELS && n > 0 && n < (int)sizeof(payload); i++)
    n += snprintf(payload + n, sizeof(payload) - n, ",%u", a[i]);
  if (n <= 0 || n >= (int)sizeof(payload) - 16) return;
  snprintf(payload + n, sizeof(payload) - n, ",diag,%04X", crc16_ccitt(payload));
  Serial.println(payload);
}

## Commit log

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2026-08-25 Refine topic + theoretical foundation + delete old-topic files
    - Add docs/01 (topic definition: longitudinal drift-robust novelty,
    two-layer RQ, killer experiment, staged study), docs/02 (theoretical
    foundation with standard/hypothesis/verify labels), docs/03 (2025-2026
    literature gap analysis plan).
    - Record owner decisions DEC-TOPIC-002/003 and DEC-INSOLE-004..008;
    rewrite claim/source ledgers and snapshot for the refined topic.
    - Append compressed conversation part 2 to the archive.
    - Delete all air-cushion/AAC artifacts (docs, cad, diagrams, simulation,
    pipeline, experiments, outputs, src, input baseline report, SOFA scripts)
    per owner directive; history retained in git.
    - Ve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
    [CLAIM_LEDGER.csv, SOURCE_LEDGER.csv, baseplate.scad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]
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2026-08-25 research: complete prior-art kill test C21-C30; narrow novelty per industrial-SHM/conformal-abstention prior patterns
    - Verify identity/venue/DOI/authors for C21-C29; C30 mapped (C24 corrected J Biomech -> Foot 59:102094)
    - Adversarial searches on exact mechanism: integrity->false-alert suppression and abstention/coverage are established (industrial SHM, conformal selective risk); none is a plantar perturbation-injection + longitudinal-false-alert + coverage system
    - SOURCE_LEDGER +11 records (38 total); CLAIM_LEDGER: update CLM-NOV-002, add CLM-NOV-003
    - Gate 1 stays OPEN (no kill, no GAP CONFIRMED); update matrix, interim decision, gate status, DECISION_LOG, PROJECT_SNAPSHOT
    Co-authored-b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
    [CLAIM_LEDGER.csv, SOURCE_LEDGER.csv]
2026-08-25 research: C31-C40 conceptual near-neighbour attack; CLM-NOV-003 survives
    - Search 5 families (sensor quality, fault diagnosis, measurement validity, context/distribution shift, longitudinal alerting) specifically to kill CLM-NOV-003
    - No paper kills it; SOURCE_LEDGER +8 records (46 total)
    - Strengthen novelty constraints: MDC/SDC is mandatory baseline; distinguish injected measurement perturbation from biological gait change (SRC-ACM-2025-GAITCHANGE); alert-gating + longitudinal monitoring established
    - Update matrix (C31-C40 section), CLM-NOV-003, DECISION_LOG (DEC-INSOLE-011), PROJECT_SNAPSHOT; QUERY_LOG +5
    [CLAIM_LEDGER.csv, SOURCE_LEDGER.csv]
2026-08-26 Direction C: Lót giày Velostat theo dõi độ cứng mô gan chân, sàng lọc sớm nguy cơ loét bàn chân đái tháo đường
    Rebuilt on top of main (fa1b9f6). Consolidates the repo around the settled ViSEF topic (Direction C): rewritten README/docs01/PROJECT_SNAPSHOT/CLAIM_LEDGER, 00_EXPLORATION_SUMMARY + archived kill-tes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
    [2026-08-25_golden_novelty_gap_matrix.csv, CLAIM_LEDGER.csv, SOURCE_LEDGER.csv]
2026-09-13 Chốt tên đề tài găng tay + đồng bộ toàn repo sang đề tài mới
    Đề tài chính thức (DEC-TOPIC-019):
    "Nghiên cứu và phát triển găng tay thông minh hỗ trợ đánh giá và theo dõi
    chức năng vận động bàn tay trong phục hồi chức năng sau đột quỵ"
    Nội dung:
    - README.md, INDEX.md: viết lại hoàn toàn cho đề tài găng tay (bỏ DFU/smart insole).
    - docs/01_Topic_Definition.md: viết lại — tên, vấn đề, khoảng trống, novelty trung
    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
    [CLAIM_LEDGER.csv, SOURCE_LEDGER.csv]
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2026-09-19 docs: verify prior art, lock theory-phase scope, ship submittable proposal
    Batches the working tree from the 2026-09-19 research programme.
    Novelty / prior art
    - SOURCE_LEDGER.csv 140 rows, CLAIM_LEDGER.csv 24 claims, QUERY_LOG.jsonl 79 entries
    - corrected 4 stale citations in our own files (Engineering year/pages, ironHand
    venue split, patent legal status US20150233779A1 abandoned / CN116954366A pending)
    - closest competitor established: Lin et al., Sensors 2022;22(19):7212 (19 IMU +
    1 pressure ball, n=14, IRB) -> differentiation rests on the rigid preload
    sidewall + per-session reliability flag, not on a new principle
    - new: two citation errors found in docs/bao_cao/A1 (SSRN preprin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
    [CLAIM_LEDGER.csv, SOURCE_LEDGER.csv]
2026-09-29 Sync submitted outline + measurability review + report outline v3.0 (2026-09-27/29)
    - 09-27: sync baseline da nop (DECUONG PDF 26/9): F1-F14, bang nguong C1.x,
    tra loi I1-I8/L1-L3, doi hinh/GVHD, cau hinh ADS1115+INA333 (docs/02/04,
    DE_CUONG_NOP_TRUONG, protocols/07/08, ledgers, sync review)
    - 09-29: checklist M-01..M-27 + kha nang do cua bo do nghe (2C23T/load cell):
    M1-M6/C1.x deu do duoc; loai claim INT8/MAS/AAN-nguoi/triet-de/ADC-do/200Hz
    (research/notebook, DEC-INST-001, DEC-BUDGET-002, DEC-MEASURE-001)
    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
    [CLAIM_LEDGER.csv, SOURCE_LEDGER.csv]
2026-10-07 hw: xac thuc cheo finger_shell_hinge.scad bang chinh engine OpenSCAD (openscad-wasm-prebuilt), doi chieu voi ban CadQuery
    - Them render_scad_wasm.mjs: chay OpenSCAD 2025.01.19 that qua Node.js
    (goi npm openscad-wasm-prebuilt) de render .scad ra STL ngay trong
    sandbox, khong can AppImage/apt (route AppImage bi chan vi GitHub
    redirect sang release-assets.githubusercontent.com, ngoai allowlist).
    - Them cross_check.py: so the tich + bounding-box giua STL CadQuery/OCCT
    (out/*.stl) va STL OpenSCAD/CGAL (out/scad/*.stl) -> khop trong sai so
    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
    [CLAIM_LEDGER.csv, SOURCE_LEDGER.csv, assembly_closed.step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]
2026-10-07 hw: fix bug - tay don ngam cai (latch_arm) la khoi roi, khong in duoc
    Phat hien boi chu du an khi tu mo finger_shell_hinge.scad bang chinh
    OpenSCAD tren may minh: anh chup cho thay 1 manh phang noi lo lung tach
    roi khoi vo chinh o trang thai 'mo' (assembly_open).
    Xac nhan bang trimesh (check_connectivity.py, moi them): latch_arm cua
    bottom_shell dat lech ~2.8mm so voi mep vo that, khong cham vao dau ca
    o bat ky lat cat Z nao -> STL xuat ra tach thanh 2 manh doc lap (vo
    chinh ~1660mm3 + tay don+moc ~321mm3). Loi nay ton tai o CA 2 ban
    finger_shell_hinge.py (CadQuery) VA finger_shell_hinge.scad (OpenSCAD)
    - khong phai loi chuyen soan, vi cross_check.py truoc do chi so khop 2
    ban VOI NHAU nen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
    [CLAIM_LEDGER.csv, assembly_closed.step, assembly_closed.stl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]
2026-10-07 hw: them truc chot ban le (hinge_pin) vao anh lap rap - bi thieu truoc do
    Phat hien boi chu du an: 'thieu cai truc o giua ban le' - anh assembly
    truoc chi ve 2 nua vo + khop ong, khong ve chot xuyen qua, nhin nhu ban
    le rong du chi tiet chot da co san trong file (hinge_pin.stl).
    Sua ca 2 file:
    - finger_shell_hinge.py: export_assembly_state() them tham so pin=,
    ve them hinge_pin mau xam dam vao ca assembly_closed va assembly_open;
    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
    [assembly_closed.step, assembly_closed.stl, assembly_closed__pin.stl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]
2026-10-07 hw: han lien truc ban le vao nua mu tay - in 1 khoi, khong con chot roi
    Theo yeu cau chu du an: 'co dinh truc xam nay voi ban le chinh... khi in
    ra in nguyen 1 khoi chu khong can thay doi'.
    Them tham so PIN_INTEGRATED (mac dinh true) o ca finger_shell_hinge.py
    va finger_shell_hinge.scad:
    - true (moi, mac dinh): nua mu tay (top_shell) KHONG con khoan lo chot -
    truc duoc union thang vao khoi, xuat STEP/STL da bao gom san truc, in
    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
    [CLAIM_LEDGER.csv, assembly_closed.step, assembly_closed.stl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]
2026-10-07 hw: sua loi ngam cai khong khoa duoc (moc/rang lech Z 5-9mm) + bo tron cac canh
    Phat hien khi chu du an yeu cau "check lai co che chinh xac":
    - Moc ngam (latch_arm/hook, Z=11.2-12.8mm) va ca 2 nac rang (latch_catch,
    Z=2.45-3.85mm va 5.05-6.45mm) LECH NHAU 5-9mm, khong co diem giao Z nao
    -> ngam cai NHU CU KHONG THE khoa duoc, du tung chi tiet rieng le van
    in duoc binh thuong (lien khoi, dung kich thuoc).
    - Loi ton tai o CA 2 file (.py va .scad), cung 1 nguyen nhan goc (2 cong
    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
    [CLAIM_LEDGER.csv, assembly_closed.step, assembly_closed.stl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]
2026-10-07 hw: doi tiet dien khung sang dang 'vien thuoc det' (capsule) - canh hong tron, mat mu/long tay van phang
    Theo yeu cau chu du an: tiet dien hop chu nhat bo goc nho (r_in/r_out)
    nhin 'vuong, cung ngac' -> doi sang profile capsule: giu 1 doan thang
    flat_w=12mm o giua mat mu/long tay (cho hoc cam bien), con 2 canh hong
    (ban le + ngam cai) la nua elip tron lien tuc, khong con goc vuong.
    - finger_shell_hinge.py: rounded_prism() dung ellipseArc() cua CadQuery
    - finger_shell_hinge.scad: them capsule_profile_pts()/capsule_prism()
    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
    [CLAIM_LEDGER.csv, assembly_closed.step, assembly_closed.stl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]
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
